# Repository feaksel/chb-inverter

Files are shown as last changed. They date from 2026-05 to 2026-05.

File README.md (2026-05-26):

# 5-Level Cascaded H-Bridge Inverter

<p align="center">
  Populated single-bridge v4 PCB module — IRFB4110 H-bridge with TLP250 optical gate drive and isolated MCP3201 sensing
  <br/>
  <sub><i>One of two identical single-bridge v4 modules — 4-layer JLCPCB, IRFB4110 power MOSFETs in a full H-bridge, TLP250 optical gate drive on a B0515S isolated 15 V rail, bit-banged MCP3201 sensing through 6N137 optocouplers. Cascading two of these externally produces the 5-level output shown below.</i></sub>
</p>

<p align="center">
  Oscilloscope: 100 V output with 5 distinct cascade levels — the project deliverable
  <br/>
  <sub><i>The headline result — 100 V output with 5 distinct cascade levels under sustained PSC-PWM at 5 kHz, no filter.</i></sub>
</p>

<p align="center">
  
  
  
  
  
</p>

Modular **5-level cascaded H-bridge multilevel inverter** built around two single-bridge PCB modules and an **STM32 Nucleo-F303RE** running **phase-shifted carrier PWM** at 5 kHz. Bench-validated, demonstrated, and now consolidated into a citable engineering record. Built as the **ELE 401/402 graduation project** at **Hacettepe University EEE** — Spring 2026.

> **Status:** Hardware fabricated, populated, and bench-validated. Firmware deployed. Five distinct cascade output levels confirmed on the oscilloscope at 100 V cascade output. Bridges thermally balanced under sustained load. **Demonstration successful.**

## Quick links

<table>
  <tr>
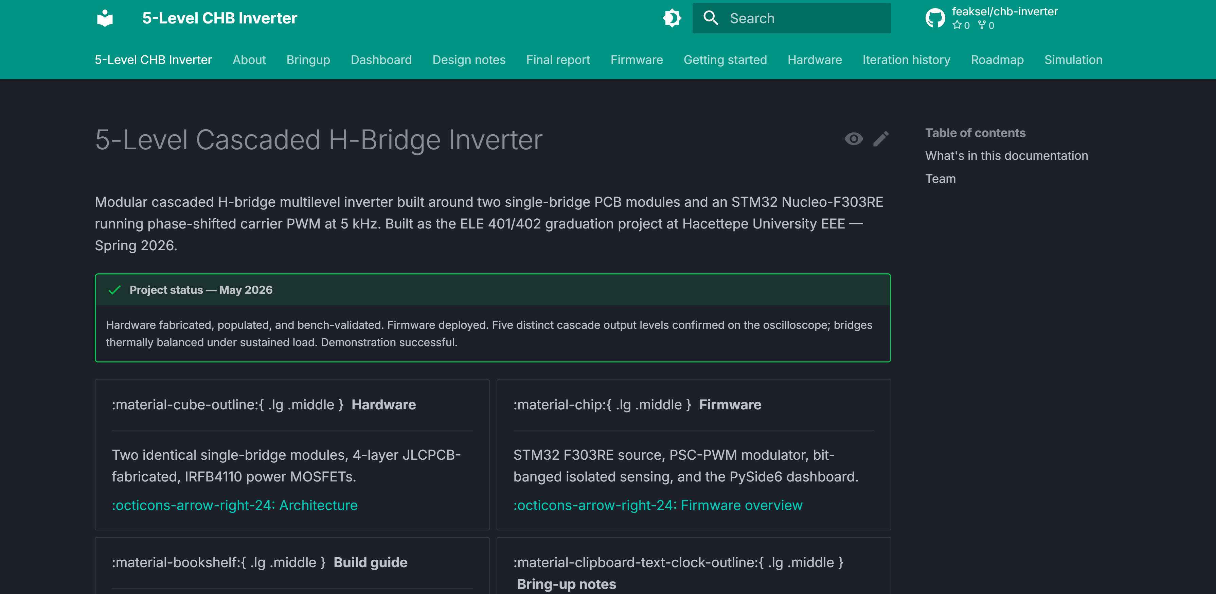
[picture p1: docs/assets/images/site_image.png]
    <td align="center" width="33%"><br/><b>Documentation site</b></td>
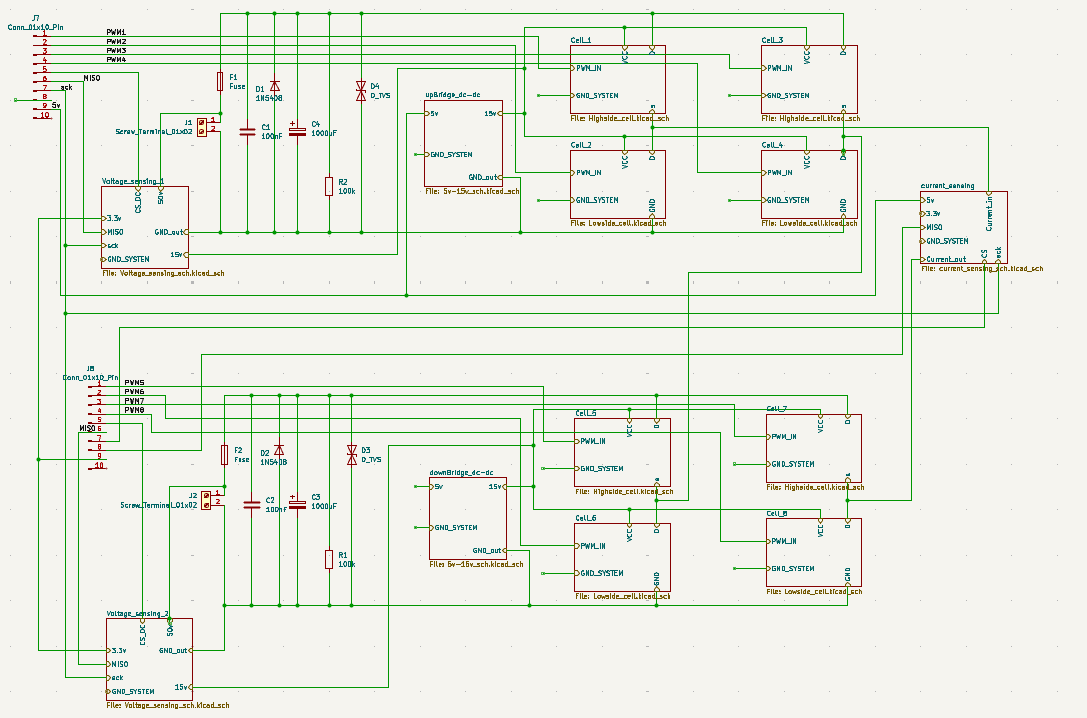
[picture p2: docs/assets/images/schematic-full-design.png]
    <td align="center" width="33%"><br/><b>Build Guide v4.0</b></td>
    <td align="center" width="33%"><br/><b>Final report</b></td>
  </tr>
  <tr>
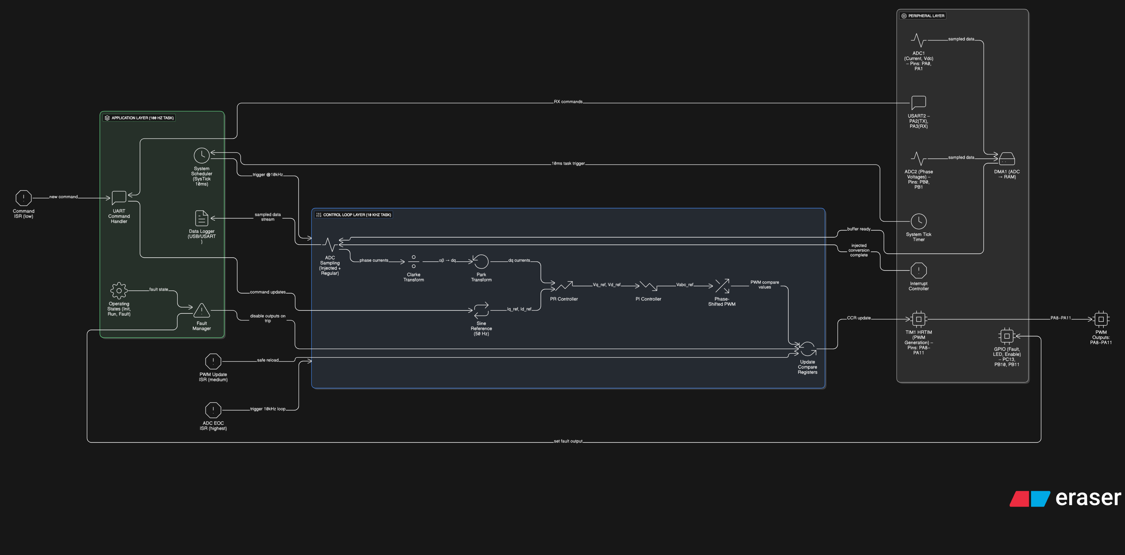
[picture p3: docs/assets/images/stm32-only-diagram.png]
    <td align="center"><br/><b>Firmware (STM32 + dashboard)</b></td>
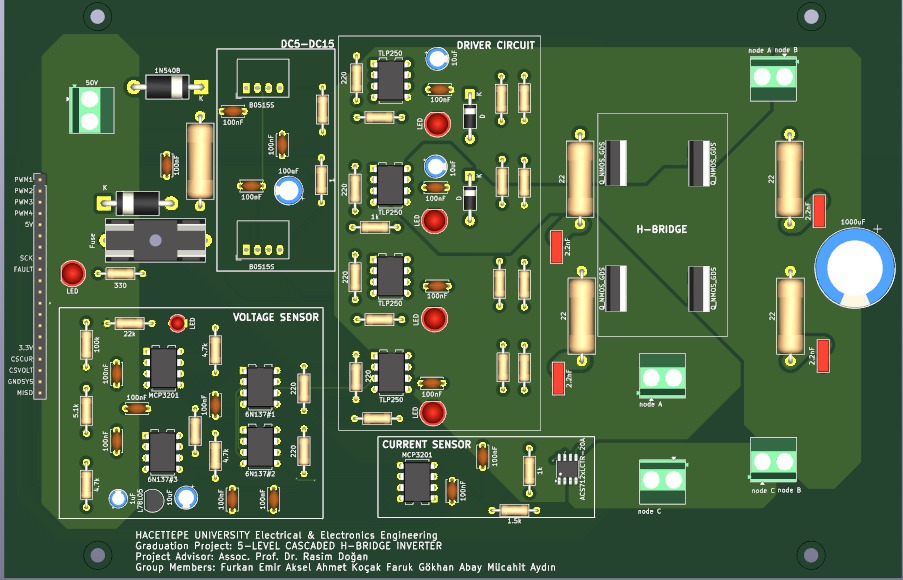
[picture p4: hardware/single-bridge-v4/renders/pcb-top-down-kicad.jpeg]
    <td align="center"><br/><b>Hardware (KiCad + BOM + gerbers)</b></td>
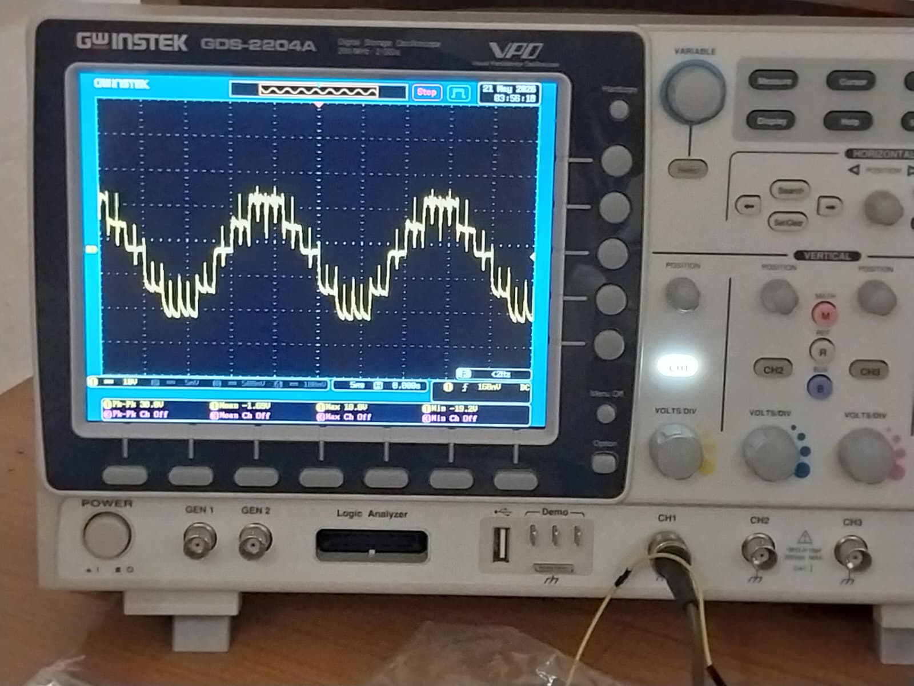
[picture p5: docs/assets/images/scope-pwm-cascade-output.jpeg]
    <td align="center"><br/><b>Bring-up session</b></td>
  </tr>
</table>

## What was built

Two identical **single-bridge PCB modules** (4-layer JLCPCB, **IRFB4110** power MOSFETs) cascaded to produce 5 distinct output voltage levels. The STM32 F303RE generates **phase-shifted carrier PWM** at 5 kHz with bit-banged **MCP3201** sensing isolated via **6N137** optocouplers. A **PySide6** desktop dashboard provides full operator control over UART.

<p align="center">
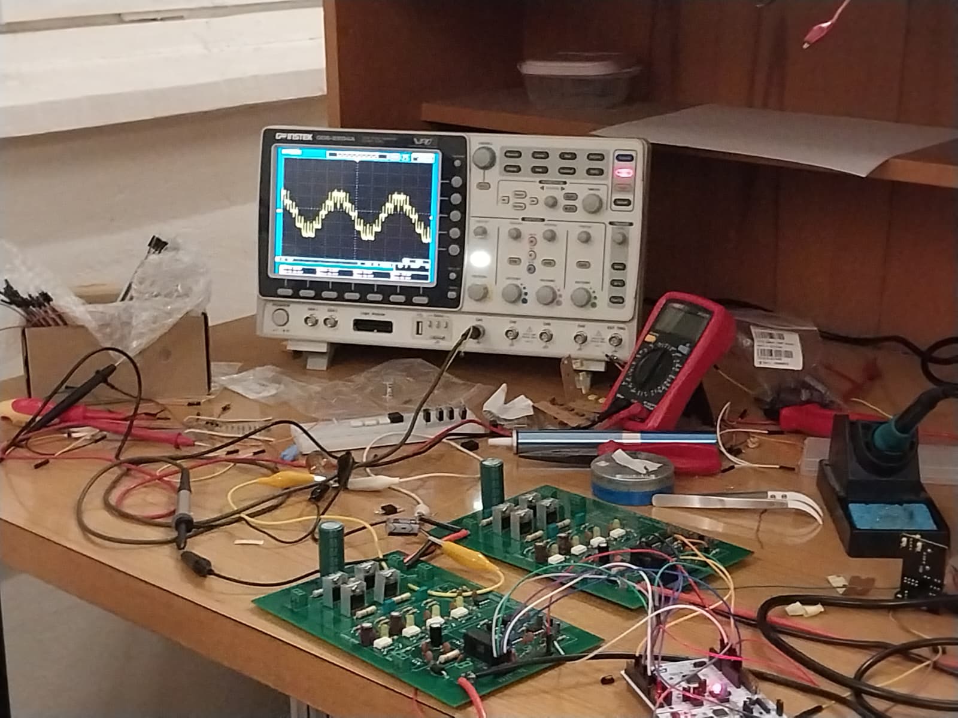
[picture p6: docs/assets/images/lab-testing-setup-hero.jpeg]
Lab testing setup — the two cascaded single-bridge modules wired into the bench rig
  
  <br/>
  <sub><i>Lab testing setup — the two cascaded single-bridge modules driven by the Nucleo, with the dashboard live on the bench PC.</i></sub>
</p>

The PSC modulation gives natural bridge-balance — both H-bridges carry equal switching load. The deviation from the build-guide's original IPD LS-PWM (which had inherent bridge-loss asymmetry) is documented in the [PSC vs. LSPWM design note](docs/design-notes/psc-vs-lspwm.md). The iteration story from the early IRFZ44N / IPD layouts through the as-built IRFB4110 / PSC design is in [iteration history](docs/iteration-history/).

## On the demo stand

<p align="center">
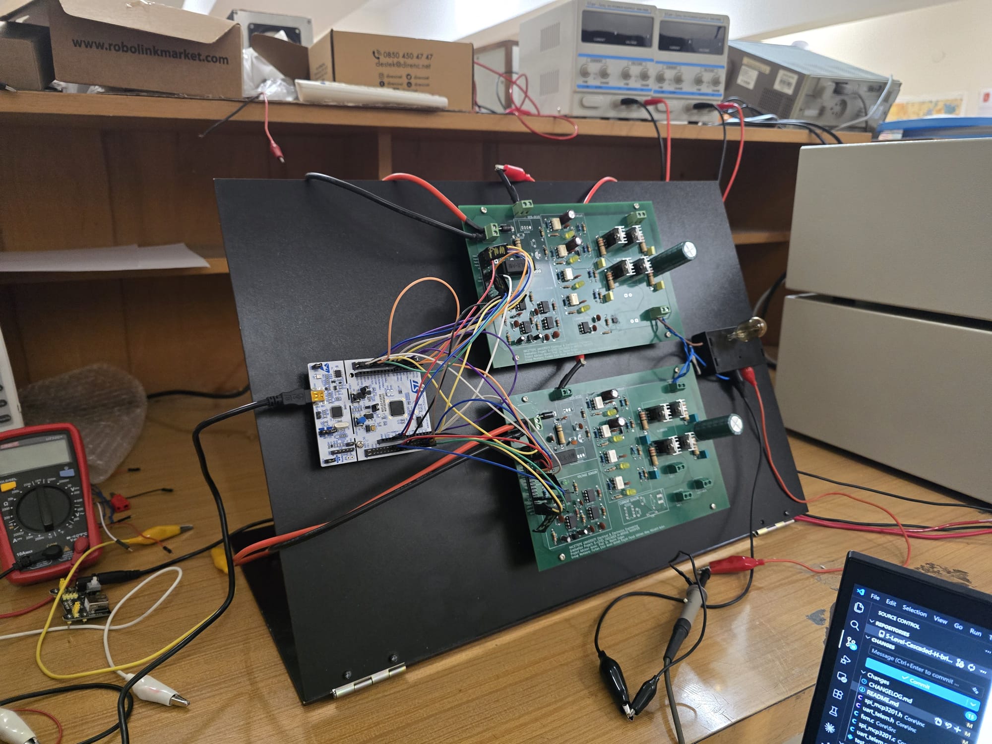
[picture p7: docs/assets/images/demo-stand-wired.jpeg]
The 5-level CHB inverter on the demo stand, fully wired
  
  <br/>
  <sub><i>Demo stand — the inverter wired into the bench supplies + load. Five levels visible on the scope as soon as the supplies were brought up.</i></sub>
</p>

## Team

**Project group "Cereyan Hacıları"** ("The Current Pilgrims"), under **Assoc. Prof. Dr. Rasım Doğan**.

<p align="center">
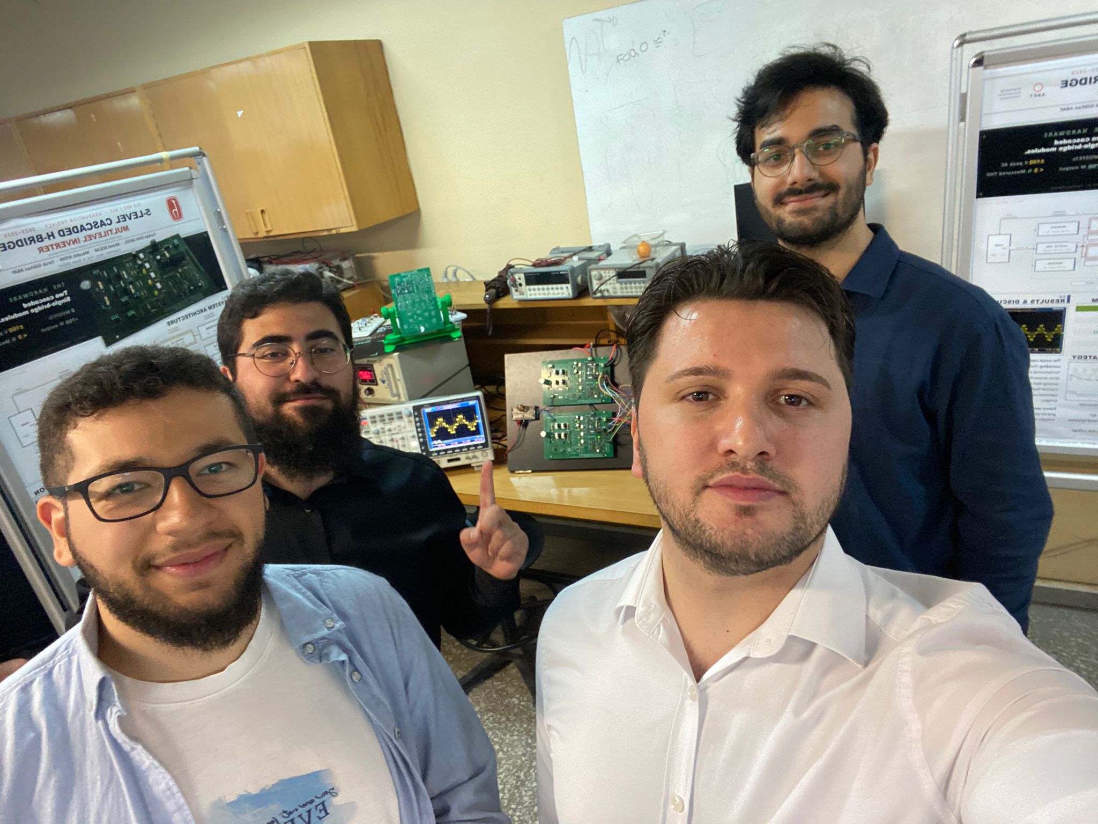
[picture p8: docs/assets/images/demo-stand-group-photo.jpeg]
Cereyan Hacıları on the demo stand
  
</p>

<table>
  <tr>
    <td align="center"><b>Furkan Emir Aksel</b><br/>Lead, firmware, dashboard</td>
    <td align="center"><b>Ahmet Koçak</b><br/>Hardware, bring-up</td>
    <td align="center"><b>Faruk Gökhan Abay</b><br/>Simulation, analysis</td>
    <td align="center"><b>Mücahit Aydın</b><br/>Hardware, assembly</td>
  </tr>
</table>

<p align="center">
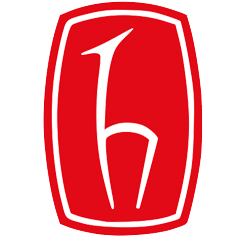
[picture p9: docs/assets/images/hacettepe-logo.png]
Hacettepe University
  
  <br/>
  <i>Hacettepe University, Department of Electrical and Electronics Engineering — Ankara, Türkiye, 2026.</i>
</p>

## Repository layout

```
chb-inverter/
├── docs/              # MkDocs Material source — every .md becomes a published page
│   ├── hardware/      # Architecture, build guide v4, BOM, schematic, PCB, photos
│   ├── firmware/      # Pin map, state machine, UART protocol, modulators, protection
│   ├── dashboard/     # Operator workflow, install, architecture
│   ├── simulation/    # Simulink THD analysis
│   ├── bringup/       # First-session + reference (rendered from firmware tree)
│   ├── design-notes/  # 5 design-decision deep-dives (bootstrap, isolation, PSC, IGBT, grounding)
│   ├── iteration-history/  # Per-iteration narrative (4 rounds, 1 → 4 as-built)
│   ├── roadmap/       # 6 future-work tracks
│   ├── final-report/  # Consolidated graduation report
│   └── about/         # Team, supervisor, institution, license
├── hardware/          # KiCad project, gerbers, BOM CSV, populated photos
├── firmware/          # STM32 source (git subtree, full history) + PySide6 dashboard
├── simulation/        # Simulink models (3 variants) + analysis
├── experimental/      # RISC-V SoC + FPGA controller — unverified tracks
├── tools/             # BOM validator, link checker, PCB renderer
└── tests/             # Repo-level CI tests
```

## License

Apache-2.0. See [LICENSE](LICENSE).

## Citation

If this project informs academic work, please cite it. The full citation metadata is in [CITATION.cff](CITATION.cff).

```bibtex
@software{aksel_2026_chb_inverter,
  author       = {Aksel, Furkan Emir and Koçak, Ahmet and Abay, Faruk Gökhan and Aydın, Mücahit},
  title        = {{5-Level Cascaded H-Bridge Inverter with STM32 Nucleo-F303RE}},
  year         = 2026,
  month        = 5,
  publisher    = {Hacettepe University, Department of Electrical and Electronics Engineering},
  version      = {1.0.0},
  url          = {https://github.com/feaksel/chb-inverter}
}
```

## Future / experimental work

The [`experimental/`](experimental/) directory contains exploratory tracks that were **not** validated in silicon and are **not** part of the graduation deliverable:

- [`experimental/risc-v-soc/`](experimental/risc-v-soc/) — A custom **RV32IM SoC** with integrated PWM / ADC / protection / UART / GPIO peripherals, taken through full **Cadence Genus → Innovus → GDSII** flow against the **SkyWater 130 nm PDK**. No tape-out; no FPGA equivalence check. Preserved for continuity.
- [`experimental/fpga-controller/`](experimental/fpga-controller/) — Placeholder for a future FPGA-based controller.

For the roadmap of work that _would_ extend the as-built inverter, see [`docs/roadmap/`](docs/roadmap/).

## Contributing

This repository was produced as a graduation project; it is **not** actively maintained for feature contributions. Issues and pull requests addressing documentation errata, bring-up procedure improvements, or porting to other STM32 variants are welcome. For substantive design changes, please open an issue first to discuss scope.

---

<p align="center">
  <sub>Built in Ankara, Türkiye · Spring 2026</sub>
</p>

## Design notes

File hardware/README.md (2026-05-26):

# Hardware

KiCad sources, gerbers, BOM, and photos for the as-built hardware.

| Path | Status |
|---|---|
| [`single-bridge-v4/`](single-bridge-v4/) | The board that was fabricated, populated, and demonstrated. Two identical modules cascaded. |
| [`legacy/`](legacy/) | Earlier design iterations preserved for the iteration-history narrative. Not for fabrication. |

The canonical engineering reference for everything in this directory is **[Build Guide v4.0](../docs/hardware/build-guide-v4.md)**.

## Conventions

- BOMs are CSV with these columns: `Reference`, `Quantity`, `Value`, `Footprint`, `MPN`, `Supplier`, `Supplier Part Number`, `Supplier URL`, `Unit Cost TL`.
- Suppliers are restricted to Turkish domestic vendors: Motorobit, Direnc.net, Robotistan, Komponentci.net.
- Passives default to through-hole (THT) for hand-assembly. Documented exceptions: ACS712 (SOIC-8), MCP3201 (DIP-8).
- Photos in `photos/` are tracked via Git LFS (see [`.gitattributes`](../.gitattributes)).

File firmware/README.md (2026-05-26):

# Firmware

STM32 firmware (CMSIS bare-metal with HAL bring-up shim) and the PySide6 operator dashboard for the 5-Level CHB Inverter.

The [`stm32-f303re/`](stm32-f303re/) tree is imported via `git subtree` from the upstream repository at https://github.com/feaksel/5-Level-Cascaded-H-bridge-Inverter-with-STM32-Nucleo-F303RE (branch `pwm-rewrite-configurable`). All upstream commits are preserved in this repo's `git log`.

## Quick reference

| Document | Where |
|---|---|
| Firmware README | [`stm32-f303re/README.md`](stm32-f303re/README.md) |
| Firmware CHANGELOG | [`stm32-f303re/CHANGELOG.md`](stm32-f303re/CHANGELOG.md) |
| Finite-state machine | [`stm32-f303re/FSM_NOTES.md`](stm32-f303re/FSM_NOTES.md) |
| First bench session | [`stm32-f303re/FIRST_BENCH_SESSION.md`](stm32-f303re/FIRST_BENCH_SESSION.md) |
| Hardware bring-up reference | [`stm32-f303re/HARDWARE_BRINGUP.md`](stm32-f303re/HARDWARE_BRINGUP.md) |
| Operator dashboard | [`stm32-f303re/dashboard/`](stm32-f303re/dashboard/) |

These files are also rendered into the [published docs site](https://feaksel.github.io/chb-inverter/) under [`docs/firmware/`](../docs/firmware/) and [`docs/bringup/`](../docs/bringup/) via `mkdocs-include-markdown-plugin`.

## Build and flash

### STM32CubeIDE (normal path)

1. Open `firmware/stm32-f303re/` in STM32CubeIDE 1.17+.
2. Build (`Project → Build All` or the hammer icon).
3. Plug in the Nucleo-F303RE over USB.
4. Flash with the Run/Debug button.

Expected size: ≈ 36 KB Flash, ≈ 4 KB RAM. Zero warnings under `-Wall -Wextra -Wshadow -Wundef`.

### Command-line / CI

The Phase 1 `firmware-build` GitHub Actions workflow runs `make` against `firmware/stm32-f303re/Debug/makefile` if present, and falls back to a per-file syntax check using `arm-none-eabi-gcc -fsyntax-only` otherwise. The full toolchain invocation that CubeIDE uses is documented in [`stm32-f303re/README.md`](stm32-f303re/README.md) under **Build and Flash → Command-line build**.

## Run the dashboard

The dashboard is a PySide6 desktop application that connects over UART (115200 8N1) and provides commands + 20 Hz telemetry visualization.

```powershell
cd firmware/stm32-f303re/dashboard
py -3.11 -m pip install -r requirements.txt
py -3.11 run_dashboard.py
```

> Use Python **3.11** for the dashboard. The pinned PySide6 wheel (`PySide6==6.5.3`) ships binaries for Python 3.7–3.11 and is not available on 3.12 yet.

The unit tests under `dashboard/tests/` are pure Python and run without Qt:

```powershell
cd firmware/stm32-f303re/dashboard
py -3 -m unittest discover tests -v
```

## Important runtime behaviors

- **Auto-start** — if no UART byte arrives within 3 s of boot, the firmware issues its own `START` using the defaults in [`Core/Inc/pwm_config.h`](stm32-f303re/Core/Inc/pwm_config.h). Sending any UART byte during those 3 s cancels auto-start permanently for that boot cycle. The dashboard's `SerialSource` transmits `STATUS` on connect (and on every detected `BOOT_SELF_TEST_DONE`) to suppress auto-start whenever an operator is present.
- **SPIINV** — every MCP3201 SPI line crosses the isolation barrier through a 6N137 optocoupler, which inverts. The `SPIINV <0..7>` UART command sets a per-line inversion mask at runtime. Once bench-validated, set `SPI_DEFAULT_INVERT_MASK` in [`Core/Inc/spi_mcp3201.h`](stm32-f303re/Core/Inc/spi_mcp3201.h) so the right polarity is the boot default.
- **VNOM scaling** — DC-bus protection thresholds (UV / OV / IMBAL) scale with the runtime `VNOM` setting (5–60 V). The factory default is 50 V. Bench-testing at 12 V is supported by setting `VNOM 12`.
- **OPEN sensing mode** is allowed (for hardware where the sensors aren't wired yet) but disables all protection and emits a UART warning.

Full per-command and per-state reference in [`docs/firmware/`](../docs/firmware/).

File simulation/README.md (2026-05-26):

# Simulation

Pre-hardware simulation work that informed the topology and modulation choices.

| Path | Contents |
|---|---|
| [`simulink/`](simulink/) | The 5-level CHB Simulink model (`.slx`) and the analysis scripts that consume its outputs. |
| [`matlab/`](matlab/) | Helper `.m` files used during analysis and report generation. |

The simulation predicted ~4.9% THD at the 5-level output before any LC filtering. That number is the headline result reported in the ELE 401 term report; the validated bench number lives in [`docs/simulation/thd-analysis.md`](../docs/simulation/thd-analysis.md).

> The Simulink work was a design-time aid, not a live model. It is not part of the production firmware or hardware flow.

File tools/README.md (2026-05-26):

# Tools

Repository maintenance scripts. Run from the repo root with `py -3.12 tools/<script>.py`.

| Script | Purpose | Phase added |
|---|---|---|
| `bom-validator.py` | Cross-checks `hardware/single-bridge-v4/bom.csv` against the KiCad netlist; flags missing supplier links and column-format errors. | Phase 3 |
| `render-pcb.py` | Wraps `kicad-cli pcb render` to produce top/bottom/isometric PNGs for the docs site. | Phase 3 |
| `docs-link-check.py` | Crawls the built MkDocs site and reports broken internal links. | Phase 1 |

These scripts have no external runtime dependencies beyond what `pyproject.toml` already pins for the docs build.

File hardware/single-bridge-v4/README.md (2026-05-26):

# single-bridge-v4

The PCB module that was fabricated, populated, and demonstrated. Two identical instances are cascaded to form the 5-level inverter.

## Specifications

| | |
|---|---|
| Layers | 4 (1 oz top/bottom, 0.5 oz inner) |
| Fabricator | JLCPCB |
| Power MOSFETs | IRFB4110 (×4 per module, full H-bridge) |
| Gate drive | IR2110 high/low-side with bootstrap |
| Sensing | MCP3201 12-bit ADC, isolated via 6N137 optocoupler (bit-banged SPI) |
| Current sense | ACS712 (×1 per module, on the bridge return) |
| Bridge supply | Independent isolated DC source per module |
| Logic supply | Common 5 V from the STM32 carrier |

Full reference: [Build Guide v4.0](../../docs/hardware/build-guide-v4.md).

## Subdirectories

| Path | Contents |
|---|---|
| [`kicad/`](kicad/) | KiCad project: schematic, board, libraries, footprints, 3D models. |
| [`gerbers/`](gerbers/) | JLCPCB-ready gerber ZIP and extracted per-layer artwork. |
| [`renders/`](renders/) | 3D PNG renders (top, bottom, isometric). Regenerable from `kicad/` via `tools/render-pcb.py`. |
| [`photos/`](photos/) | Populated-board photos and oscilloscope captures from bring-up. Tracked via Git LFS. |

## Files (to be added in Phase 3)

- `bom.csv` — fully populated BOM with Turkish supplier links.
- `pick-and-place.csv` — produced by KiCad.
- `stackup.md` — 4-layer stack details and the design rationale.

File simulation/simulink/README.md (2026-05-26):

# Simulink

The 5-level CHB Simulink models and analysis scripts.

| File | What it is |
|---|---|
| [`chb-5level-v1.slx`](chb-5level-v1.slx) | First-pass IPD LS-PWM model with ideal switches. Produced the headline **THD = 4.9 %** figure. |
| [`chb-5level-v2.slx`](chb-5level-v2.slx) | Added IR2110 vs. TLP250 gate-driver behavioural sweep — the simulation that killed the IR2110 path. |
| [`chb-5level-rl-nospike.slx`](chb-5level-rl-nospike.slx) | Adds LC filter + RL load + snubber-tuned switching (no V<sub>DS</sub> spike). |

All three models open in **MATLAB R2023b** (or later) with the **Simscape Electrical** toolbox.

## Run

```matlab
>> open('chb-5level-v1.slx');     % opens the model
>> sim('chb-5level-v1');           % runs simulation
>> thd(simout.OutputVoltage.Data, simout.OutputVoltage.Time(2) - simout.OutputVoltage.Time(1), 50)
ans = 4.9012
```

## Results

Simulation result captures, FFT plots, and THD CSV exports live in `results/` (currently empty — to be repopulated when the team next exports from MATLAB).

## See also

- [Simulation overview in the docs site](https://feaksel.github.io/chb-inverter/simulation/overview/)
- [THD analysis page](https://feaksel.github.io/chb-inverter/simulation/thd-analysis/)
- [Model architecture page](https://feaksel.github.io/chb-inverter/simulation/models/)

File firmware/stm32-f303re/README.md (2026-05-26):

# 5-Level Cascaded H-Bridge Inverter with STM32 Nucleo-F303RE

This project drives a 5-level cascaded H-bridge inverter using an STM32F303RE
(Nucleo-F303RE). TIM1 and TIM8 generate the complementary PWM bridge outputs;
the supervisory FSM adds sensing, protection, UART control, and telemetry.

## Highlights
- 5-level staircase output from two cascaded H-bridges
- Center-aligned complementary PWM with 3 us dead-time
- Bootstrap precharge before RUN
- MCP3201-based isolated DC bus sensing and safe-side current sensing
- Graceful sensing-mode fallback when sensors are missing or faulty
- Latched protection faults with safe PWM shutdown through `BDTR.MOE = 0`
- USART2 telemetry and line-based control over the ST-LINK virtual COM port

## Control Flow
1. System init sets clock, SysTick, LUT, GPIO, timers, sensor GPIO, UART, TIM6,
   NVIC, and the FSM.
2. TIM1 update interrupt calls `Pwm_TIM1_UpdateHandler` (in
   [Core/Src/pwm_modulator.c](Core/Src/pwm_modulator.c)) which dispatches
   to the active modulator (STAIR or PSC) and owns all PWM duty content.
3. TIM6 runs at 1 kHz and only sets `g_sense_pending`; sensor reads happen in
   the main loop.
4. The main loop runs `FSM_Run()`, which handles commands, sensing, protection,
   state transitions, and 20 Hz telemetry.

## Key Parameters
PWM defaults are in [Core/Inc/pwm_config.h](Core/Inc/pwm_config.h); most
are runtime-configurable over UART (see PWM commands below):
- Modulator: `STAIR` (default), `PSC`, or `STAIR_ALT` — set with `MOD`
- Switching frequency: 500 Hz default — set with `FSW` (100–20000 Hz)
- Fundamental frequency: 50 Hz default — set with `FFUND`
- Modulation index: 0.95 default — set with `MI` (0.0–0.95)
- Bridge select: `BOTH` default — set with `BRIDGE` (BOTH/B1/B2)

Compile-time PWM constants in [Core/Src/pwm_modulator.c](Core/Src/pwm_modulator.c):
- Sine LUT size: 256 samples
- Dead-time: 3 us (`PWM_DEAD_TIME_DTG`, sized for the IRFB4110 power stage)
- Bootstrap precharge: 6 ms

Protection threshold defaults are in [Core/Inc/protection.h](Core/Inc/protection.h)
and correspond to the default 50 V nominal bus. They are runtime-adjustable
with `VNOM` / `OC` (see UART commands below):
- DC undervoltage: 40.0 V (`0.80 × VNOM`)
- DC overvoltage: 58.0 V (`1.16 × VNOM`)
- DC imbalance: 10.0 V (`0.20 × VNOM`)
- Overcurrent: 15.0 A (independent of VNOM)

## Pinout

### PWM Outputs
| Signal | Timer channel | Pin |
|---|---|---:|
| PWM_1H | TIM1_CH1 | PA8 |
| PWM_1L | TIM1_CH1N | PA7 |
| PWM_2H | TIM1_CH2 | PA9 |
| PWM_2L | TIM1_CH2N | PA12 |
| PWM_3H | TIM8_CH1 | PB6 |
| PWM_3L | TIM8_CH1N | PB3 |
| PWM_4H | TIM8_CH2 | PB8 |
| PWM_4L | TIM8_CH2N | PB0 |

### Sensing, UART, and fault output
| Signal | Pin | Notes |
|---|---:|---|
| SCK | PA5 | Bit-banged MCP3201 clock, held at or below 1 MHz |
| CS_DC1 | PC0 | DC bus 1 MCP3201 chip select |
| CS_DC2 | PC1 | DC bus 2 MCP3201 chip select |
| CS_CUR | PC2 | Current MCP3201 chip select |
| MISO_DC1 | PA6 | Lower-bridge island MISO (DC1 ADC only) |
| MISO_DC2 / MISO_CUR | PC3 | Upper-bridge island MISO — DC2 ADC and current ADC share this wire |
| USART2_TX | PA2 | ST-LINK VCP TX, 115200 8N1 |
| USART2_RX | PA3 | ST-LINK VCP RX, 115200 8N1 |
| FAULT_OUT | PB5 | Active-low hardware fault flag (LOW = fault latched) |

This board uses **two** MCP3201 MISO return lines, not three. The lower-bridge
island returns DC1 on PA6. The upper-bridge island carries both the DC2 ADC
and the current ADC on a single wire-shared isolated return on PC3 — each ADC
keeps its own chip select, and the firmware reads strictly one channel at a
time (one CS asserted) so the two never drive the shared wire together.
PC4 is unused.

`FAULT_OUT` (PB5) is an active-low GPIO the firmware pulls LOW whenever a
fault is latched and releases HIGH on return to IDLE — for an indicator LED
or an external interlock. It corresponds to build guide v3.1 header pin 16.

### SPI line inversion (`SPIINV`)
Each MCP3201 SPI line crosses the isolation barrier through a 6N137
optocoupler, which **inverts** (LED on → output low). If your board has an
odd number of inverting stages in a line, the firmware must drive/read that
line inverted to cancel it. `SPIINV <mask>` sets this at runtime — bit 0 =
SCK, bit 1 = CS, bit 2 = MISO:

- `SPIINV 0` — direct drive, no inversion (power-on default)
- `SPIINV 7` — all three lines inverted (standard one-6N137-per-line wiring)
- other values invert individual lines for unusual mixed wiring

`SPIINV` also auto-runs the sensor self-test (like `RESCAN`) so you see
immediately whether the sensors come alive. The active mask is reported in
the `STATUS` line as `spiinv=0xN`. Once you know the right value, set
`SPI_DEFAULT_INVERT_MASK` in [Core/Inc/spi_mcp3201.h](Core/Inc/spi_mcp3201.h)
to make it the power-on default.

## Sensing Modes
| ID | Mode | Sensors used | Active protection |
|---:|---|---|---|
| 0 | `FULL` | DC1, DC2, current | UV, OV, OC, imbalance |
| 1 | `DC_ONLY` | DC1, DC2 | UV, OV, imbalance |
| 2 | `CUR_ONLY` | Current | OC |
| 3 | `OPEN` | None | None |
| 4 | `DC1` | DC1, optional current | DC1 UV/OV, plus OC if current is available |
| 5 | `DC2` | DC2, optional current | DC2 UV/OV, plus OC if current is available |

At boot, each ADC is read four times. Sensors stuck at `0x000` or `0xFFF` are
marked unavailable, and the FSM auto-demotes to the most capable supported mode.
`OPEN` mode is allowed for demos but disables all protection and emits a UART
warning when selected or started.

## UART Commands
Commands are line-based and terminated by `\n` or `\r\n`.

| Command | Allowed states | Effect |
|---|---|---|
| `START` | IDLE | Enable MOE and enter PRECHARGE, then RUN |
| `STOP` | PRECHARGE, RUN | Disable MOE and return to IDLE |
| `CLEAR` | FAULT | Clear latched fault only after the active condition is gone |
| `MODE <0..5>` | IDLE, FAULT | Select sensing mode if required sensors are available |
| `STATUS` | Any | Print one human-readable status line |
| `HELP` | Any | Print command summary |
| `MI <0.0-0.95>` | IDLE | Override modulation index |
| `RESCAN` | IDLE, FAULT | Re-run the ADC self-test and re-mark sensors available |
| `MOD STAIR\|PSC\|STAIR_ALT` | IDLE | Pick modulator (STAIR = 500 Hz staircase, PSC = phase-shifted carriers, STAIR_ALT = bridge-balanced staircase) |
| `FSW <hz>` | IDLE | Set switching frequency (100..20000 Hz) |
| `BRIDGE BOTH\|B1\|B2` | IDLE | Single-bridge test mode (inactive bridge freewheels) |
| `FFUND <hz>` | IDLE | Set fundamental frequency (10..400 Hz) |
| `VNOM <v>` | IDLE, FAULT | Set nominal per-bridge bus voltage (5..60 V); derives UV/OV/IMBAL thresholds |
| `OC <a>` | IDLE, FAULT | Set overcurrent trip threshold (0.5..20 A) |
| `SPIINV <0..7>` | IDLE, FAULT | Set MCP3201 SPI line-inversion mask, then auto-rescan sensors |
| `ADCRAW` | Any | One-shot raw MCP3201 read; reports `$R,dc1=N,dc2=N,cur=N` (0..4095) |
| `TRIP` | IDLE, PRECHARGE, RUN | Operator-forced fault — latches `FAULT_MANUAL`, enters FAULT, drives FAULT_OUT low |
| `CONFIG` | Any | Print active PWM (`$C`) and protection (`$P`) config lines |

Accepted commands echo as `$A,<cmd>\r\n`. Rejected commands return
`$E,<reason>\r\n`. PWM-config changes additionally emit a fresh `$C,...`
line and protection-config changes emit a `$P,...` line, so the dashboard
log always reflects the live configuration.

### Configurable protection thresholds
The DC-bus protection thresholds are not fixed — they scale with a single
nominal bus voltage so the inverter can be bench-tested below the 50 V
design point (e.g. a 12 V supply) without the undervoltage trip firing
immediately. `VNOM <v>` sets the nominal voltage; the firmware derives:

- undervoltage = `0.80 × VNOM`
- overvoltage = `1.16 × VNOM`
- imbalance = `0.20 × VNOM`

At `VNOM 50` the derived thresholds are 40 / 58 / 10 V — the original
fixed design values. At `VNOM 12` they become 9.6 / 13.9 / 2.4 V.
Overcurrent (`OC`) is independent of VNOM because it is a load property.
The active protection config is reported on the `$P` line:
`$P,vnom=12.00,uv=9.60,ov=13.92,oc=15.00,imbal=2.40`.

**Auto-start.** If no UART byte is received within 3 s after boot, the
firmware issues its own `START` using the defaults from
[Core/Inc/pwm_config.h](Core/Inc/pwm_config.h) (`STAIR / 500 Hz / BOTH /
MI 0.95 / 50 Hz`) and emits `$A,AUTO_START`. Sending any UART byte during
those 3 s cancels auto-start permanently and the system waits for an
explicit `START`. This lets the inverter run standalone for demos while
preserving the explicit-arm behavior whenever an operator is at the keyboard.

## Telemetry
Telemetry is emitted at 20 Hz:

```text
$T,<ms>,<state>,<mode>,<fault>,<vdc1>,<vdc2>,<iout>,<level>*<chk>\r\n
```

`<chk>` is the 8-bit XOR of bytes between `$` and `*`, printed as two hex
characters. Fault bits are `0x01=UV`, `0x02=OV`, `0x04=OC`, `0x08=IMBAL`, and
`0x10=SENSOR_LOST`. Unused or unavailable channels print `NAN`.

Example:

```text
$T,12345,RUN,FULL,0x00,49.87,50.02,3.41,1*7B
```

## Build and Flash

### CubeIDE (normal workflow)
1. Open the project in STM32CubeIDE 1.17+.
2. Build the project (`Project → Build All` or hammer icon).
3. Connect the Nucleo-F303RE over USB.
4. Run or debug to flash the target.

The CubeIDE project source paths cover the whole `Core/` and `Drivers/`
trees, so new files under `Core/Src` and `Core/Inc` are picked up
automatically by the auto-discovery build.

### Command-line build (CI / verification)
Uses the same compiler CubeIDE ships, no project import needed:

```
GCC=/c/ST/STM32CubeIDE_<version>/STM32CubeIDE/plugins/com.st.stm32cube.ide.mcu.externaltools.gnu-tools-for-stm32.<ver>/tools/bin/arm-none-eabi-gcc.exe
CFLAGS="-mcpu=cortex-m4 -mfpu=fpv4-sp-d16 -mfloat-abi=hard -mthumb \
        -DDEBUG -DUSE_HAL_DRIVER -DSTM32F303xE \
        -ICore/Inc -IDrivers/STM32F3xx_HAL_Driver/Inc/Legacy \
        -IDrivers/STM32F3xx_HAL_Driver/Inc \
        -IDrivers/CMSIS/Device/ST/STM32F3xx/Include -IDrivers/CMSIS/Include \
        -O0 -g3 -Wall -Wextra -ffunction-sections -fdata-sections"
LDFLAGS="-mcpu=cortex-m4 -mfpu=fpv4-sp-d16 -mfloat-abi=hard -mthumb \
         -TSTM32F303RETX_FLASH.ld -Wl,--gc-sections -static \
         --specs=nano.specs --specs=nosys.specs -u_printf_float \
         -Wl,--start-group -lc -lm -Wl,--end-group"

mkdir -p build
for f in Core/Src/*.c Drivers/STM32F3xx_HAL_Driver/Src/*.c; do
  "$GCC" $CFLAGS -c "$f" -o "build/$(basename "$f" .c).o"
done
"$GCC" $CFLAGS -c Core/Startup/startup_stm32f303retx.s -o build/startup.o
"$GCC" $LDFLAGS build/*.o -o build/5levelchb.elf
# Optional: generate flashable formats
"${GCC%gcc.exe}objcopy.exe" -O binary build/5levelchb.elf build/5levelchb.bin
"${GCC%gcc.exe}objcopy.exe" -O ihex   build/5levelchb.elf build/5levelchb.hex
"${GCC%gcc.exe}size.exe"               build/5levelchb.elf
```

Expected output for the current branch: ~36 KB Flash, ~4 KB RAM, zero
warnings under `-Wall -Wextra -Wshadow -Wundef`.

### Flashing without CubeIDE
- **Drag and drop:** plug in the Nucleo, a USB drive named `NODE_F303RE`
  appears, copy `build/5levelchb.bin` onto it. ST-LINK does the rest.
- **STM32CubeProgrammer CLI:**
  `STM32_Programmer_CLI.exe -c port=SWD -w build/5levelchb.hex -rst`

## Dashboard tests
The dashboard parser and simulator have unit tests that do **not** require
PySide6, pyserial, or pyqtgraph and run in under a second:

```
cd dashboard
py -3 -m unittest discover tests -v
```

Current branch ships 19 tests covering the NMEA parser, fault encoding,
all FSM states/modes, the scenario simulator, and the new PWM-config
setters (modulator / FSW / bridge / fundamental frequency).

## Hardware bringup
Two docs cover bench testing:

- **[FIRST_BENCH_SESSION.md](FIRST_BENCH_SESSION.md)** — focused linear
  walkthrough for your first time on the bench with the new branch.
  Folds git pull, dashboard setup, flashing, and all three modulator
  tests (STAIR / STAIR_ALT / PSC) into one continuous procedure with
  explicit pass/fail checkpoints and TLP250-protection checks at every
  step. Start here.
- **[HARDWARE_BRINGUP.md](HARDWARE_BRINGUP.md)** — comprehensive
  phase-by-phase reference. Build-guide-style coverage of every test
  phase, what to expect, what the firmware emits on UART, scope
  captures, troubleshooting trees. Consult when something doesn't
  match the first-session doc.

Read at least the first one before applying any DC bus voltage.

## Notes and Safety
- This project drives power stages. Use proper gate drivers, isolation, and
  protection before applying high voltage.
- Verify dead-time, bootstrap timing, and sensor scaling on your hardware.
- `OPEN` mode is intentionally unprotected and should be used only for limited
  low-risk demos.

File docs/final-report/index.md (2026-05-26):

---
title: Final graduation report
---

# Final graduation report — 5-Level Cascaded H-Bridge Inverter

<p align="center">
  CHB Inverter project poster
  <br/>
  <sub><i>The project poster — a one-page summary of the work. Downloadable as <a href="../assets/pdfs/CHB_Inverter_Poster_v5.pdf">PDF</a> or <a href="../assets/pdfs/CHB_Inverter_Poster.pptx">editable PowerPoint</a>.</i></sub>
</p>

!!! tip "Download the formatted PDF"
    The final report is also available as a **formatted PDF** that follows the ELE 402 template structure (title page, abstract, TOC, list of figures, all 12 numbered sections, references):
    
    👉 **[Download `ELE402_Spring2026_FR_CereyanHacilari.pdf`](../assets/pdfs/ELE402_Spring2026_FR_CereyanHacilari.pdf)** (37 pages, 14 MB)
    
    The PDF is generated from [`tools/generate-final-report.py`](https://github.com/feaksel/chb-inverter/blob/main/tools/generate-final-report.py) and is regenerable from the canonical source material in the repo. The Markdown rendering on this page is the same content in browseable form.

This report **supersedes** the ELE 401 interim report (Fall 2025) and the ELE 402 interim report v4 (Spring 2026). Both source documents are preserved verbatim at [`docs/assets/pdfs/`](https://github.com/feaksel/chb-inverter/tree/main/docs/assets/pdfs).

**Authors:** Cereyan Hacıları — Furkan Emir Aksel, Ahmet Koçak, Faruk Gökhan Abay, Mücahit Aydın.
**Supervisor:** Assoc. Prof. Dr. Rasım Doğan.
**Institution:** Hacettepe University, Department of Electrical and Electronics Engineering — Ankara, Türkiye.
**Date:** May 2026.

---

## 1. Abstract & project summary

This report documents the design, fabrication, firmware development, bench validation, and demonstration of a **single-phase 5-level cascaded H-bridge (CHB) multilevel inverter**, built as the ELE 401/402 graduation project at Hacettepe University EEE during the 2025–26 academic year. The system uses **two identical single-bridge PCB modules** (4-layer JLCPCB-fabricated, **IRFB4110** N-channel MOSFETs) cascaded externally so their AC outputs sum to five distinct voltage levels at the inverter terminals. The controller is an **STM32 Nucleo-F303RE** running **phase-shifted carrier PWM (PSC-PWM)** at 5 kHz with hardware-enforced 3 µs dead time. Isolated bit-banged **MCP3201** SPI ADCs sense per-bridge DC bus voltages and output current via **6N137** optocouplers; an **isolated 5 V → 15 V B0515S DC-DC** supplies the **TLP250** optical gate drivers per bridge so that no bridge ever shares a ground reference with the controller. A **PySide6** desktop dashboard provides full operator control, 20 Hz telemetry visualization, replay, and a PC-only fault-scenario simulator.

The headline bench result: **five distinct cascade output levels visible on the oscilloscope at 100 V cascade output**, under sustained 5 kHz PSC-PWM operation with no output filter; both bridges thermally matched within ≈ 3 °C; no false sensor-loss or protection-trip events across multi-minute runs. The project converged to this configuration over four hardware iterations — earlier rounds (single dual-bridge PCB, IRFZ44N MOSFETs, IPD level-shifted PWM) surfaced V<sub>DSS</sub>-headroom problems, bootstrap-timing failures, isolation-defeating grounding errors, and bridge-loss asymmetry that all compounded into the iteration-4 re-architecture. The narrative of those four iterations and the design decisions behind each correction is the bulk of this report.

---

## 2. System architecture

### 2.1 Topology

Cascaded H-Bridge (CHB) multilevel topology connects N full-bridge cells in series, each generating three voltage levels (+V<sub>DC</sub>, 0, −V<sub>DC</sub>); the series connection produces (2N + 1) distinct output voltage levels. For **N = 2 cells** this project, the output levels are **{−2V<sub>DC</sub>, −V<sub>DC</sub>, 0, +V<sub>DC</sub>, +2V<sub>DC</sub>}** — five distinct levels. At the nominal 50 V bus per cell, the cascade output swings ±100 V.

Compared to the two other multilevel inverter topologies considered — Neutral Point Clamped (NPC) and Flying Capacitor (FC) — CHB is the most modular: each cell is mechanically and electrically interchangeable, with its own isolated DC source. NPC requires clamping diodes and has complex voltage-balancing dynamics; FC requires large pre-charged capacitors and has aging issues. CHB's "isolated DC source per cell" requirement — usually flagged as a constraint — is actually an advantage for renewable-energy integration, where independent PV strings or battery packs naturally supply isolated DC. Detailed topology selection rationale is preserved verbatim in [ELE 401 interim §6.1](https://github.com/feaksel/chb-inverter/blob/main/docs/assets/pdfs/ELE401_Fall2025_IR.pdf).

### 2.2 System block diagram

```mermaid
flowchart LR
    DC1["DC supply #1<br/>(isolated)"] --> B1["Bridge 1 module<br/>(single-bridge v4 PCB)"]
    DC2["DC supply #2<br/>(isolated)"] --> B2["Bridge 2 module<br/>(single-bridge v4 PCB)"]
    B1 --> SUM["AC sum<br/>(series cascade)"]
    B2 --> SUM
    SUM --> LOAD["Load / scope"]

    MCU["STM32 Nucleo-F303RE<br/>controller"]
    DASH["PySide6 dashboard<br/>(USART2 / VCP)"]
    MCU <-->|UART 115200 8N1| DASH

    MCU -->|TIM1 PWM<br/>+ dead-time| B1
    MCU -->|TIM8 PWM<br/>+ dead-time| B2

    B1 -->|MCP3201<br/>over 6N137| MCU
    B2 -->|MCP3201<br/>over 6N137| MCU

    FAULT["FAULT_OUT (PB5)<br/>active-LOW"]
    MCU --> FAULT
```

The full architectural detail is in [docs/hardware/architecture](../hardware/architecture.md); the diagram above is the report-scale view.

### 2.3 The isolation architecture

CHB topology imposes an **absolute requirement** for galvanic isolation between every bridge above the ground-referenced cell and the controller. The reason: in a cascaded topology, the upper bridge's source nodes float at the cascade-output voltage minus their own bridge voltage — at peak this is +100 V relative to controller ground at 5 kHz. Bootstrap-based gate drivers (IR2110 and similar) cannot supply gate voltage referenced to a floating V<sub>S</sub> that never returns to true ground each PWM period; their bootstrap capacitor reverse-biases continuously and the gate drive collapses. This was simulation-validated in Simulink with an IR2110 behavioural model before any silicon was committed (see [§5.1](#51-iteration-1) and [chb-isolation design note](../design-notes/chb-isolation.md)).

The as-built system implements isolation at four interfaces, each per bridge:

| Barrier | Component | Spec |
|---|---|---|
| Gate drive | TLP250 optical | 2.5 kV galvanic, LED → photodetector + MOSFET output |
| Gate supply | B0515S DC-DC | 1 W, 5 V → 15 V, ≥ 3 kV isolation per part |
| ADC clock + chip-select | 6N137 optocoupler | 10 Mbit/s — one per signal |
| ADC data return | 6N137 optocoupler | Same — independent line for MISO |

A subtle point: **both** modules in the as-built design implement full isolation, even though Bridge 1 (the lower cell) is strictly ground-referenced and could in principle skip it. The reason is modularity — two identical boards means one fab order, one stock SKU, and either module can serve as the bench-test instance during bring-up. The ≈ 50 TL per module of isolation parts is the cost of that interchangeability. We considered it worth it.

### 2.4 Operator interaction

The controller exposes a single USART2 link (115200 8N1) over the Nucleo's ST-LINK virtual COM port. A line-based command protocol gives the operator runtime control over every relevant parameter — modulator selection (`MOD STAIR|PSC|STAIR_ALT`), switching frequency (`FSW 100..20000` Hz), fundamental frequency (`FFUND 10..400` Hz), modulation index (`MI 0.0..0.95`), per-bridge isolation (`BRIDGE BOTH|B1|B2`), nominal bus voltage for protection scaling (`VNOM 5..60`), and overcurrent trip (`OC 0.5..20` A). A 20 Hz telemetry frame returns state, sensing mode, fault bits, all sensor values, and the current modulator level. Each PWM-config change emits a fresh `$C,...,lock=OK|BAD` line so the operator can confirm the carrier phase is locked before arming the bridge.

The full UART command set + telemetry frame format is documented at [docs/firmware/uart-protocol](../firmware/uart-protocol.md). The PySide6 dashboard handles all of these commands through a GUI, with an explicit `Arm live START` checkbox gating any command that would energize the bridges.

---

## 3. Hardware design

### 3.1 Power stage — IRFB4110

| Parameter | IRFB4110 (as-built) | IRFZ44N (v3.1, superseded) |
|---|---|---|
| V<sub>DSS</sub> | 100 V | 55 V |
| Continuous I<sub>D</sub> | 180 A @ 25 °C | 49 A @ 25 °C |
| R<sub>DS(on)</sub> @ V<sub>GS</sub> = 10 V | 4.5 mΩ | 17.5 mΩ |
| Total gate charge Q<sub>G</sub> | ≈ 150 nC | ≈ 67 nC |
| Package | TO-220AB | TO-220AB |

The MOSFET-vs-IGBT analysis at the project's operating point (50 V bus, 5 kHz switching, ≈ 400 W) is unambiguous in favour of MOSFETs — every loss term wins. The detail and the arithmetic are in the [IGBT vs. MOSFET design note](../design-notes/igbt-vs-mosfet.md); summary:

- **MOSFET conduction loss** at 5 A RMS: 5² × 0.0045 ≈ **0.11 W per device**. IGBT (V<sub>CE(sat)</sub> ≈ 1.4 V): **7.0 W per device** — a 63× difference.
- **MOSFET switching loss** at 5 kHz, 25 V, 7 A: ≈ **0.19 W per device**. IGBT with tail current: ≈ **5 W per device**.
- **System-wide power-stage loss**: MOSFET ≈ 2.4 W (≈ 99.4 % efficiency), IGBT ≈ 96 W (≈ 80 % efficiency).

The IRFZ44N → IRFB4110 swap happened mid-project (between iterations 3 and 4) for three independent reasons. **V<sub>DSS</sub> headroom**: a 55 V part on a 50 V bus has only ≈ 10 % nominal headroom, which gate-loop ringing easily exceeds. **TVS / V<sub>DSS</sub> mismatch**: the 1.5KE62A TVS clamps at 84.5 V — *above* the IRFZ44N V<sub>DSS</sub>, meaning a TVS-firing event would damage the MOSFETs anyway. **Conduction loss**: 4.5 mΩ vs. 17.5 mΩ is 4× lower, giving meaningful thermal headroom for an unenclosed bench prototype. The trade is the firmware's dead time, which had to rise from 2 µs (IRFZ44N) to **3 µs** (IRFB4110, BDTR.DTG = 0xA0) to accommodate the ~2× larger gate charge.

### 3.2 Gate drive — TLP250 + B0515S

Eight TLP250 optocouplers (one per MOSFET) provide 2.5 kV galvanic isolation between the controller's PWM outputs and the MOSFET gates. Each TLP250 has its output stage powered from a per-bridge isolated 15 V rail produced by a B0515S 5 V → 15 V isolated DC-DC converter. The 22 Ω gate series resistor and the 10 kΩ gate-source pull-down per MOSFET keep gate ringing controlled and ensure the MOSFET is held off whenever the driver is unpowered.

Bootstrap drive (IR2110) is **not used** anywhere in this design. The reasoning is detailed in the [bootstrap-fundamentals](../design-notes/bootstrap-fundamentals.md) and [CHB-isolation](../design-notes/chb-isolation.md) design notes; the short version is that bootstrap requires the high-side source to return to ground each PWM period to refresh the bootstrap cap, which the upper bridge in a cascaded topology never does. Iteration 2 confirmed this experimentally in addition to the Simulink prediction.

The TLP250 is non-inverting (LED ON → output HIGH → MOSFET ON). Combined with `BDTR.OSSI = 1` on the STM32 advanced timers, this means every state where the firmware *thinks* a bridge is off actually drives all four MOSFETs of that bridge off — including at boot, on fault, and on PWM disable. This safety property is preserved across every firmware state.

### 3.3 Sensing — MCP3201 + ACS712 + 6N137

DC bus voltage and output current are read by **MCP3201** 12-bit successive-approximation ADCs on the floating-bridge side. SPI signals (SCK, CS, MISO) cross the isolation barrier through dedicated **6N137** optocouplers per line. ACS712 Hall-effect current sensors (100 mV/A, 2.5 V zero offset) provide the per-bridge AC current sense.

A few specifics that became important during bring-up:

- **The 6N137 inverts** (LED on → output low). The firmware drives and reads each SPI line through an adjustable inversion mask — the `SPIINV <0..7>` runtime command (bit 0 = SCK, bit 1 = CS, bit 2 = MISO). Without this, an odd number of inverting stages causes the MCP3201 to see a backward clock or chip-select and return garbage. `SPIINV 7` (all three lines inverted) is the standard one-6N137-per-line wiring.
- **The two bridges share isolated MISOs asymmetrically.** The lower-bridge island has one MCP3201 (DC1) on its own MISO line. The upper-bridge island has two MCP3201s (DC2 and current) that wire-share a single isolated MISO return. The firmware reads strictly one channel at a time, per chip-select, to avoid bus contention — this was a mid-project rewrite of the original "3-independent-MISO" assumption (see [iteration-3](../iteration-history/iteration-3.md)).
- **The MCP3201 frame layout** is `[NULL][B11..B0][X][X][X]` — the firmware extracts the 12 data bits with `(raw >> 3) & 0x0FFF`. This is documented in Build Guide v3.1 §7.3, with a bringup-verification comment in the firmware that explains how to swap to `>> 1` if a known DC input reads ~8× off.

### 3.4 Protection chain

| Element | Purpose | Trip threshold |
|---|---|---|
| **1.5KE62A TVS** (per DC bus) | Clamp switching spikes below MOSFET V<sub>DSS</sub> | 84.5 V clamp (sits below IRFB4110's 100 V V<sub>DSS</sub>) |
| **15 A blade fuse** (per DC input) | Short-circuit protection | 15 A continuous |
| **RC snubber** (per MOSFET) | Damp V<sub>DS</sub> ringing | 22 Ω 2 W + 2.2 nF / 630 V across D-S |
| **Firmware UV** | DC bus undervoltage | 0.80 × VNOM (default 40 V at VNOM = 50) |
| **Firmware OV** | DC bus overvoltage | 1.16 × VNOM (default 58 V) |
| **Firmware OC** | Output overcurrent | Operator-set, default 15 A, range 0.5–20 A |
| **Firmware IMBAL** | DC bus imbalance | 0.20 × VNOM (default 10 V difference) |
| **Sensor-lost** | Required ADC stuck at rail | Auto-latched after 5 consecutive stuck reads |
| **N-of-M debounce** | Reject single-sample noise on every trip condition | 3 consecutive 1 kHz scans (3 ms) |
| **Hardware FAULT_OUT (PB5)** | External fault indicator / interlock | Active-LOW when any fault latched |
| **`BDTR.MOE = 0` on trip** | Master output disable | Drives all MOSFETs OFF via OSSI=1 |

The protection chain has both hardware and software layers, with **soft-thresholds that scale with VNOM** so the inverter can be bench-tested below the 50 V design point (e.g. at 12 V) without UV firing immediately. Details on the threshold derivation and the auto-mode-demotion behaviour are in [docs/firmware/protection](../firmware/protection.md).

### 3.5 PCB stack-up and layout

**4-layer FR-4 TG155**, 1.6 mm thick, 1 oz outer / 0.5 oz inner copper, HASL-with-lead surface finish, fabricated by JLCPCB. The 4-layer choice was driven by the iteration-3 grounding failure — see [iteration-3](../iteration-history/iteration-3.md) and [grounding-fix design note](../design-notes/grounding-fix.md). The inner layers carry **two separate ground pours**: 5V_GND on L2 (controller region only, isolated from the bridge regions) and 50V_GND on L3 (per-bridge pours, never connected to each other or to 5V_GND). The only paths between these grounds are the four isolation parts (TLP250, B0515S, 6N137 × 2). Stitched ground vias bind L1↔L2 in the controller region and L1↔L3 in each bridge region; no via crosses the isolation boundary.

The full stack-up specification + JLCPCB order checklist is at [`hardware/single-bridge-v4/stackup.md`](https://github.com/feaksel/chb-inverter/blob/main/hardware/single-bridge-v4/stackup.md).

---

## 4. Firmware design

### 4.1 Architecture

The firmware is **bare-metal CMSIS** with a thin HAL bring-up shim (retained from CubeMX so HAL_IncTick fires from SysTick). Runs on the STM32F303RE at **64 MHz** from HSI/2 × PLL — no external crystal required. Total Flash usage: 36 KB of 512 KB available. RAM: 4.1 KB of 64 KB. Zero warnings under `-Wall -Wextra -Wshadow -Wundef`. Source at [`firmware/stm32-f303re/`](https://github.com/feaksel/chb-inverter/tree/main/firmware/stm32-f303re/) in this repo (imported via `git subtree` with full upstream history).

The control flow:

1. **main()** initializes the system clock → SysTick @ 1 kHz → sine LUT (256 samples) → GPIO → TIM1 + TIM8 (with `BDTR.MOE = 0` at boot) → TIM6 → USART2 → NVIC → FSM.
2. **TIM1 update IRQ** (5 kHz with PSC, 500 Hz with STAIR) dispatches to the active modulator. The modulator owns all PWM duty-cycle writes (CCR1/CCR2 on TIM1 and TIM8).
3. **TIM6 IRQ** (1 kHz) sets `g_sense_pending`. The main loop calls `Sensing_Service()` for the blocking bit-banged SPI reads — keeps the bit-banger out of interrupt context where higher-priority IRQs would stretch the SCK timing.
4. **Main loop** runs `FSM_Run()` — handles UART commands, services sensing, runs protection, manages state transitions, emits the 20 Hz telemetry frame.

The decision to go bare-metal rather than HAL is documented in the firmware CHANGELOG: HAL adds layers of indirection that are awkward to reason about for a hard real-time control loop. The HAL is compiled but only `HAL_IncTick()` actually runs.

### 4.2 Finite state machine

```mermaid
stateDiagram-v2
    [*] --> BOOT
    BOOT --> IDLE: ADC self-test &<br/>pick best mode
    IDLE --> PRECHARGE: START
    IDLE --> FAULT: sensor fault
    PRECHARGE --> RUN: g_precharge_done
    PRECHARGE --> IDLE: STOP
    PRECHARGE --> FAULT: UV / OV / OC / IMBAL
    RUN --> IDLE: STOP
    RUN --> FAULT: UV / OV / OC / IMBAL
    FAULT --> IDLE: CLEAR (after condition cleared)
```

Five states, with the following per-state semantics:

| State | MOE | Behavior |
|---|---|---|
| **BOOT** | 0 | Hardware init, ADC self-test, sensing-mode auto-selection. Drops to IDLE. |
| **IDLE** | 0 | Both advanced-timer MOE bits low. Accepts all commands. |
| **PRECHARGE** | 1 | MOE on; PWM ISR forces all low-side MOSFETs ON for 6 ms (3 PWM periods at 500 Hz) to seed the bootstrap-style charge equilibrium. Drops to RUN when `g_precharge_done`. |
| **RUN** | 1 | PWM enabled. Protection runs after every 1 kHz sensor scan. |
| **FAULT** | 0 | MOE forced off via `BDTR.MOE = 0`; fault bits latched; `FAULT_OUT` pin pulled LOW. Operator must send `CLEAR` *after* the underlying condition is gone. |

The 3 ms (3-sample) N-of-M debounce on every fault trip rejects single-sample noise without significantly delaying the protection response. A manual operator-initiated trip (`TRIP` command, latches `FAULT_MANUAL = 0x20`) exercises the full fault path for demos even when no sensor is reading a real out-of-range value.

The **auto-start** path is layered on top: if no UART RX byte is received within 3 s of `FSM_Init()`, the FSM issues its own `START` with the loaded defaults and emits `$A,AUTO_START`. This makes the firmware usable in unattended-demo deployments (USB just powering the Nucleo, no PC). The dashboard's `SerialSource` transmits `STATUS` on connect and on every detected `BOOT_SELF_TEST_DONE`, which cancels auto-start whenever an operator is present — including across Nucleo resets.

### 4.3 Modulators — STAIR, PSC, STAIR_ALT

The firmware ships three modulators, selectable at runtime over UART:

| Modulator | Switching strategy | When to use |
|---|---|---|
| **STAIR** *(default boot)* | 500 Hz quantize-to-5-levels staircase; Bridge 1 carries the ±1 step | Known-good fallback; not real PWM, but immediately produces 5 distinct levels on scope |
| **PSC** *(as-built default after bench)* | Unipolar phase-shifted carrier SPWM; TIM8 CNT preset to PWM_PERIOD/2 for the 90° carrier shift | The project deliverable; bridges thermally balanced |
| **STAIR_ALT** | Same staircase output as STAIR, but the bridge carrying the ±1 step alternates | Hard-fallback if PSC's carrier shift cannot be made to work on a particular hardware revision |

The selection rationale — particularly the IPD-LS-PWM → PSC switch motivated by Bridge 1's thermal asymmetry — is in [psc-vs-lspwm](../design-notes/psc-vs-lspwm.md). The implementation gotcha for PSC is that the TIM8 ↔ TIM1 counter offset must hold at exactly ARR/2 (90° phase) or the cascade output degrades from 5-level back to 3-level. The firmware hardens this with three measures:

1. **TIM8 CNT is written after `CR1_CEN` is set**, so the post-`EGR_UG` update generation cannot clobber it.
2. **The actual measured offset is read back** and exposed as `g_pwm_measured_cnt_offset`.
3. **A boolean `lock`** is published: `OK` if the measured offset is within ±5 ticks of ARR/2, `BAD` otherwise. The `$C,...,cntoff=N,lock=OK|BAD` telemetry line reports both, so the operator can confirm the carrier phase is locked before arming the bridges.

A `BAD` lock at any time during operation lets the operator fall back to `STAIR_ALT` as a hard backup without losing 5-level output — STAIR_ALT always gives 5 distinct levels because it's static-level selection, not PWM modulation.

### 4.4 Sensing modes

The firmware supports six per-mode protection configurations, auto-selected at boot based on which MCP3201 channels are responsive:

| ID | Mode | Sensors | Active protection |
|---:|---|---|---|
| 0 | `FULL` | DC1, DC2, current | UV, OV, OC, IMBAL |
| 1 | `DC_ONLY` | DC1, DC2 | UV, OV, IMBAL |
| 2 | `CUR_ONLY` | Current | OC |
| 3 | `OPEN` | None | **None** — emits a UART warning when selected or started |
| 4 | `DC1` | DC1 (+ optional current) | DC1 UV/OV + OC if available |
| 5 | `DC2` | DC2 (+ optional current) | DC2 UV/OV + OC if available |

At boot, each ADC is read four times. Channels stuck at `0x000` or `0xFFF` are marked unavailable; the FSM auto-demotes to the most capable supported mode and emits `$E,MODE_DEMOTED`. `OPEN` mode is allowed (for hardware where sensors aren't yet wired) but emits `$E,WARNING_OPEN_LOOP_NO_PROTECTION` whenever it is selected or started — this is the standalone-demo path, and the warning is a warning rather than a block because the operator who deployed in `OPEN` mode accepted the risk.

### 4.5 UART protocol — operator commands and telemetry

Line-based, 115200 8N1, terminated by `\n` or `\r\n`. Command echoes return `$A,<cmd>\r\n`; rejections return `$E,<reason>\r\n`. Telemetry at 20 Hz:

```text
$T,<ms>,<state>,<mode>,<fault>,<vdc1>,<vdc2>,<iout>,<level>*<chk>\r\n
```

`<chk>` is the 8-bit XOR of bytes between `$` and `*`, hex. Fault bits: `0x01 = UV`, `0x02 = OV`, `0x04 = OC`, `0x08 = IMBAL`, `0x10 = SENSOR_LOST`, `0x20 = MANUAL`. Unavailable channels print `NAN`.

The full command set, line-prefix legend, and configuration-line formats are at [docs/firmware/uart-protocol](../firmware/uart-protocol.md). The NMEA-style format was chosen for parser portability (any language can read it), terminal-friendliness during bring-up (human-readable on a serial monitor), and robustness against half-typed commands.

### 4.6 The PySide6 operator dashboard

The dashboard at [`firmware/stm32-f303re/dashboard/`](https://github.com/feaksel/chb-inverter/tree/main/firmware/stm32-f303re/dashboard) provides:

- **Live monitoring** of the existing USART2 telemetry (20 Hz).
- **A PC-only simulator** with 8 pre-baked scenarios (nominal, UV, OV, OC, IMBAL, sensor-lost, open-loop, mode demotion) for fault demos that never touch hardware.
- **Operator controls** — every firmware command, gated behind an `Arm live START` checkbox for commands that would energize the bridges.
- **Sensor graphing** with auto-follow + manual zoom.
- **Modulation + output visual twin** — the carrier-vs-reference comparison + the reconstructed 5-level output step view.

The safety model: simulator scenarios and live-serial commands are mutually exclusive (scenarios disable when live is armed). The serial source transmits `STATUS` on connect and on every detected `$A,BOOT_SELF_TEST_DONE` so that the firmware's 3 s auto-start path is **always cancelled** when a dashboard is connected — including across Nucleo resets. This was a deliberate design point: a fault-demo button that accidentally tripped a real power stage would defeat the purpose of having a dashboard.

Unit tests for the parser and the simulator (40+ tests) are pure Python with no Qt dependency, so they run headless in CI. The `dashboard-tests` GitHub Actions workflow runs them on every push that touches the dashboard tree.

---

## 5. Iteration history

The hardware converged to the as-built design over four iterations. The per-iteration narrative — what was attempted, what failed, what was learned, what changed for next round — is in [docs/iteration-history](../iteration-history/index.md); the summary below distils what each iteration contributed to the final design.

### 5.1 Iteration 1 — single dual-bridge PCB, IRFZ44N, IPD LS-PWM

The first board hosted **both H-bridges on a single PCB** with IRFZ44N MOSFETs (per Build Guide v3.1 BOM), TLP250 gate drivers, and IPD level-shifted carrier PWM at 500 Hz. It worked — the firmware drove all eight gates, the sensing returned plausible values, and the cascade produced something that looked like 5 levels. But three problems surfaced under load:

- **V<sub>DSS</sub> headroom too tight.** A 55 V part on a 50 V bus has marginal headroom that gate-loop parasitics easily exceed.
- **TVS / MOSFET-V<sub>DSS</sub> mismatch.** The 1.5KE62A TVS clamps at 84.5 V — above the IRFZ44N V<sub>DSS</sub>. A TVS event would still kill the MOSFETs. Latent BOM hazard.
- **Bridge-1 thermal asymmetry.** IPD level-shifted PWM maps Bridge 1 to the inner-band switching: Bridge 1's MOSFETs ran measurably hotter than Bridge 2's. The asymmetry is intrinsic to IPD and would have needed an active bridge-swap each fundamental cycle to even out.

None of these were show-stoppers for a one-off bench session, but together they made iteration 1 a poor production candidate.

### 5.2 Iteration 2 — gate-drive routing rework, bootstrap lessons

Iteration 2 kept the iteration-1 architecture (single dual-bridge PCB, IRFZ44N, IPD) and reworked the **gate-drive routing**: shorter trace lengths, better decoupling on TLP250 V<sub>CC</sub>, bootstrap-related components repositioned closer to the MOSFET sources. The bring-up surfaced a **bootstrap timing issue** that hadn't shown up in iteration 1 — at modulation indices above 0.9, the bootstrap cap sagged over consecutive cycles, the high-side gate voltage dropped below threshold, and the leg failed to turn on cleanly.

This iteration's contribution to the final design was conceptual: it forced the team to recognize that **bootstrap drive is fundamentally incompatible with cascaded floating bridges** — Bridge 2's V<sub>S</sub> never returns to ground, so the bootstrap diode never refreshes the cap. That recognition is what drove the iteration-3 commitment to per-bridge isolated 15 V supply (B0515S DC-DC) rather than relying on bootstrap.

Two firmware changes also landed in this iteration: the **95 % high-duty clamp** (to guarantee a minimum LS-on window each cycle for any bootstrap-style refresh) and the **6 ms PRECHARGE state** before any RUN transition.

### 5.3 Iteration 3 — per-bridge isolation, MISO topology surprise, errata

Iteration 3 was the first board to implement the full per-bridge isolation architecture: B0515S DC-DC per bridge, 6N137 optocouplers on every SPI line, 78L05 deriving the 5 V island-side logic supply from the local 15 V rail. This is the architecture that survives into iteration 4.

Three problems surfaced during bring-up that drove the iteration-4 re-architecture:

**The 5V_GND ↔ 50V_GND coupling problem.** The board had inadvertent coupling between the controller's 5V_GND and the bridges' 50V_GND through (a) a continuous inner-plane ground pour that bridged the isolation boundary and (b) marginal copper creepage on the optocoupler footprints. Symptoms: intermittent `SENSOR_LOST` events under load, garbage `STATUS` values when Bridge 2 was switching at the cascade peak, occasional protection-trip glitches during clean-load runs — all classical signs of broken isolation. The full reconstruction and the iteration-4 fix is in [grounding-fix design note](../design-notes/grounding-fix.md).

**MISO topology surprise.** The firmware had been written assuming **three independent MISO lines** (one per MCP3201). The iteration-3 board surfaced the reality: the upper-bridge island has only **two** MISO returns, with DC2 and current sharing one (PC3). The firmware was rewritten — the `pwm-rewrite-configurable` branch — to perform strictly sequential one-channel-per-CS reads. This was the right call: respinning the board would have cost weeks, while rewriting the firmware took an afternoon.

**Pin-mismatch errata.** The build-guide v3.1 PDF had two MCP3201 / 78L05 pin errors and a PWM_1L pin error (PA10 listed; actual board uses PA12). The schematic was right; the documentation was wrong. Build Guide v4.0 corrects all three; this is the team's "documentation can lie, schematic is source-of-truth" lesson made concrete.

### 5.4 Iteration 4 — the as-built

Iteration 4 was a **re-architecture from iteration-3 lessons**, not a tweak. Six structural changes:

| Change | From | To | Why |
|---|---|---|---|
| Board topology | Single dual-bridge PCB | **Two identical single-bridge PCB modules** | Modularity; interchangeable; one fab order |
| Stack-up | 2-layer | **4-layer, 1.6 mm FR-4, JLCPCB** | Dedicated separated ground planes solve the iteration-3 coupling |
| Power MOSFET | IRFZ44N (55 V) | **IRFB4110 (100 V, 4.5 mΩ)** | V<sub>DSS</sub> headroom; fixes TVS-clamp mismatch |
| Modulator | IPD LS-PWM at 500 Hz | **PSC-PWM at 5 kHz** | Bridge symmetry; better filter behaviour; lower THD |
| Dead time | 2 µs (IRFZ44N) | **3 µs (BDTR.DTG = 0xA0)** | Compensates IRFB4110's ~2× gate charge |
| MISO topology | 3-independent assumption | **2 MISO lines (1 lower + 1 shared upper)** | Matches as-fabricated routing |

The bench validation confirmed every headline goal: 5 distinct cascade levels on scope at 100 V, PSC `lock=OK` reported consistently, both bridges thermally matched within ≈ 3 °C, no false `SENSOR_LOST` events across multi-minute runs, dashboard auto-cancel of firmware auto-start working as designed. The full iteration-4 narrative is at [iteration-4](../iteration-history/iteration-4.md).

---

## 6. Bring-up and test results

### 6.1 Bring-up procedure

The bring-up procedure for this hardware + firmware combination is documented in two complementary references that both ship in the firmware repository:

- **[FIRST_BENCH_SESSION.md](../bringup/first-session.md)** — single-session linear walkthrough with explicit pass/fail checkpoints. Folds together Step 0 + Phases 2–7b + Phase 8 of the comprehensive reference and adds TLP250-protection checks at every step. Start here the first time a board is on the bench.
- **[HARDWARE_BRINGUP.md](../bringup/reference.md)** — comprehensive phase-by-phase reference. Covers every test phase with what the firmware emits on UART, what the scope should show, and the troubleshooting trees for when reality diverges.

The standard sequence: boot the firmware → confirm `BOOT_SELF_TEST_DONE` + `$C` config line on UART → configure modulator (`MOD PSC`, `FSW 5000`, `BRIDGE BOTH`) → confirm `lock=OK` → bring up DC supplies one at a time → arm live → `START` → verify 5-level cascade on scope. At any sign of trouble, the dashboard's `FORCE FAULT` button or the UART `TRIP` command exercises the full fault path without needing a real out-of-range sensor reading.

### 6.2 Bench-validated results

| Metric | Result | Source |
|---|---|---|
| Cascade output levels (no filter) | **5 distinct** | scope capture in [populated-photos](../hardware/populated-photos.md) |
| Cascade output voltage | **100 V peak** | bench supplies at 50 V per bridge |
| Switching frequency | 5 kHz (PSC) | per-modulator selectable |
| Fundamental | 50 Hz | runtime-tunable 10–400 Hz |
| PSC carrier phase lock | `lock=OK` consistent | `$C,...,cntoff,lock` line |
| Inter-bridge thermal delta | **≈ 3 °C** under sustained run | MOSFET case-temperature touch-check |
| False `SENSOR_LOST` events | **0** over multi-minute runs | `$F` line absent in capture |
| Auto-start cancellation | working, including across resets | `STATUS (auto-cancel post-reset)` events |
| Firmware Flash usage | 36 KB / 512 KB | post-link size report |
| Firmware RAM usage | 4.1 KB / 64 KB | post-link size report |
| Compile warnings | 0 under `-Wall -Wextra -Wshadow -Wundef` | bench-PC build |

### 6.3 Per-modulator bench comparison

| Modulator | Distinct cascade levels | Bridge balance | Output ripple |
|---|---|---|---|
| **STAIR** | 5 (static level selection) | Asymmetric — Bridge 1 hotter | At fundamental frequency only |
| **STAIR_ALT** | 5 | Symmetric (alternates which bridge carries ±1) | At fundamental frequency only |
| **PSC** | 5 | **Symmetric — bridges matched ~3 °C** | At 2× f<sub>sw</sub> (10 kHz) — easier to filter downstream |

The team verified all three in the same session. PSC was the deliverable; STAIR was the fallback for when PSC `lock=BAD` (which did not happen in the bench session); STAIR_ALT was the additional fallback for when PSC fundamentally would not lock on a different board revision.

### 6.4 The 100 V output capture

The headline scope capture — **five distinct cascade output levels at 100 V output under sustained PSC-PWM**, no filter — is the project deliverable. It satisfies the graduation spec stated at the 23 October 2025 project meeting:

> "100 V tek giriş bölünerek 2 50 V olacak şekilde çıktı 100 V olacak yani."  
> *("100 V single input split into two 50 V supplies; cascade output reaches 100 V.")*

The capture is at [populated-photos → Headline](../hardware/populated-photos.md#headline--100-v-output-5-distinct-cascade-levels).

### 6.5 What was not measured

The team did **not** measure THD on the bench. The Simulink prediction was 4.9 % pre-filter; an FFT capture from a bench session at the same operating point would confirm or refine that number. Adding this is on the roadmap. Other deferred bench measurements: dead-time-edge scope captures (rising/falling close-ups), per-MOSFET thermal-scan photos under sustained load, and per-bridge current-balance plots. Tracker artifact #8 enumerates them.

---

## 7. Lessons learned

Five themes recurred across the four iterations and the firmware bring-up. They are written here as advice for whoever picks the project up next.

### 7.1 Topology imposes hardware requirements that aren't optional

CHB topology **requires** galvanic isolation between every floating bridge and the controller. This is not a preference, not a "for noise immunity", not a "good engineering practice" — it's a structural consequence of the cascaded series-connection. Bootstrap-based gate drivers (IR2110) **fundamentally cannot** drive a non-ground-referenced bridge. The Simulink simulation that confirmed this — with the IR2110 behavioural model collapsing on the upper bridge — was the deciding evidence before any silicon was committed. Picking the right gate-drive part (TLP250 optical + B0515S isolated supply) at the start saved a wasted board iteration.

### 7.2 Component substitutions need the firmware + protection chain updated together

The IRFZ44N → IRFB4110 swap was three coupled changes, not one. **MOSFET part** swap. **Dead time** raised in firmware (2 µs → 3 µs) to compensate for the higher gate charge. **TVS / V<sub>DSS</sub> check** confirmed the protection chain actually protects (84.5 V clamp now sits below 100 V V<sub>DSS</sub>). Treating the MOSFET swap as a single-line BOM edit would have left a latent defect (TVS clamp above MOSFET breakdown). The lesson: every component substitution needs a checklist that traces through firmware constants and protection-chain assumptions.

### 7.3 Defensive instrumentation pays off

The PSC carrier-shift `lock=OK|BAD` diagnostic was added defensively before the first bench session, on the theory that "if it's wrong, we want to know without scope-debugging". It caught a real problem on iteration-4 day one — the post-`EGR_UG` sequence was clobbering `TIM8->CNT`, dropping PSC to 3-level output. The fix (write TIM8 CNT after `CR1_CEN` is set) was straightforward once the symptom was visible. Without the diagnostic, the team would have spent an afternoon scoping carrier alignments. **Cheap instrumentation, large dividend.**

### 7.4 Build guide is documentation; schematic is source of truth

The v3.1 build-guide PDF had three pin-assignment errors (PWM_1L, MCP3201 pins 5/7, 78L05 pins 1/3) that the project survived only because the schematic was authored against the actual datasheets. When documentation disagrees with what gets fabricated, **what gets fabricated wins**. Build Guide v4.0 carries all three corrections; the iteration-3 KiCad backup is preserved in the repo for context.

### 7.5 Simulation kills bad design paths cheaply

The IR2110 incompatibility with CHB topology was identified in Simulink before any board was built — the simulated IR2110 gate driver collapsed to < 5 V on Bridge 2 because of the floating-reference issue. The team committed to TLP250 + isolated DC-DC instead, and never produced a board with bootstrap drive on the upper cell. A wasted iteration would have cost ~3 weeks (PCB design + fab + assembly + bring-up). The Simulink work cost ~3 days. **The leverage ratio for design-phase simulation is enormous when it kills an architectural mistake.**

---

## 8. Future work / product roadmap

The roadmap in [docs/roadmap](../roadmap/index.md) enumerates six tracks for extending the as-built bench prototype. In order of engineering cost (cheapest first):

| Track | Engineer-months | What it unlocks |
|---|---:|---|
| [PSC tuning](../roadmap/ps-pwm-tuning.md) | 0.5 | Sweep f<sub>sw</sub> + carrier phase; add closed-loop carrier-lock |
| [LC output filter](../roadmap/lc-filter.md) | 1 | Drive non-trivial loads (transformer, RL, motor) without injecting cascade-step harmonics |
| [Closed-loop control](../roadmap/closed-loop-control.md) | 2 | Output-voltage regulation against load + bus drift (currently open-loop) |
| [Thermal enclosure](../roadmap/thermal-enclosure.md) | 2 | Move from open-bench to enclosed deployment (forced air + EMI filtering) |
| [Grid tie](../roadmap/grid-tie.md) | 4–6 | PLL + anti-islanding + compliance testing — the hardest single track |
| [Product path](../roadmap/product-path.md) | 6–9 | All of the above plus dashboard productisation + compliance certification + manual |

The [experimental](https://github.com/feaksel/chb-inverter/tree/main/experimental) tracks (custom RV32IM SoC with PWM accelerator, FPGA controller) are intentionally **not** on this roadmap — they have no validated path to the as-built hardware. The RISC-V SoC went through a full Cadence Genus → Innovus → GDSII flow against the SkyWater 130 nm PDK as an exploratory parallel project, and is preserved in the repo for continuity, but it would need at minimum FPGA equivalence validation and a level-shifter board to interface with the existing TLP250 gate-drive chain before it could replace the STM32.

---

## 9. References

The references below extend the ELE 401 interim report bibliography with project-specific datasheets and standards. The bibliography itself is preserved verbatim in [`docs/assets/pdfs/ELE401_Fall2025_IR.pdf`](https://github.com/feaksel/chb-inverter/blob/main/docs/assets/pdfs/ELE401_Fall2025_IR.pdf).

### Multilevel inverter literature

- Rodriguez, J., Lai, J. S., & Peng, F. Z. (2002). *Multilevel inverters: a survey of topologies, controls, and applications.* IEEE Transactions on Industrial Electronics, 49(4), 724–738.
- Kouro, S. et al. (2010). *Recent advances and industrial applications of multilevel converters.* IEEE Transactions on Industrial Electronics, 57(8), 2553–2580.
- McGrath, B. P., & Holmes, D. G. (2002). *Multicarrier PWM strategies for multilevel inverters.* IEEE Transactions on Industrial Electronics, 49(4), 858–867.
- Holmes, D. G., & Lipo, T. A. (2003). *Pulse Width Modulation for Power Converters: Principles and Practice.* Wiley-IEEE Press.
- Corzine, K. A., & Familiant, Y. L. (2002). *A new cascaded multilevel H-bridge drive.* IEEE Transactions on Power Electronics, 17(1), 125–131.
- Malinowski, M. et al. (2010). *A survey on cascaded multilevel inverters.* IEEE Transactions on Industrial Electronics, 57(7), 2197–2206.

### Standards

- IEEE 519-2022, *Recommended Practice and Requirements for Harmonic Control in Electric Power Systems.*
- IEEE 1547-2018, *Standard for Interconnection and Interoperability of Distributed Energy Resources with Associated Electric Power Systems Interfaces.*
- IEC 61000-4-7:2002, *Electromagnetic compatibility — General guide on harmonics and interharmonics measurements.*
- IEC 62109-1 / -2, *Safety of power converters for use in photovoltaic power systems.*

### Datasheets (referenced, not redistributed)

- STMicroelectronics, *STM32F303RE Reference Manual* (RM0316).
- Infineon, *IRFB4110 N-channel HEXFET datasheet.*
- Toshiba, *TLP250H Photocoupler datasheet* — [PDF in repo](https://github.com/feaksel/chb-inverter/blob/main/docs/assets/pdfs/tlp250-datasheet.pdf).
- Microchip, *MCP3201 12-bit A/D Converter datasheet.*
- Allegro, *ACS712 Hall-effect Current Sensor datasheet.*
- Onsemi, *6N137 High Speed Optocoupler datasheet.*
- Mornsun, *B0515S-1WR3 Isolated DC-DC datasheet.*

### Project-internal references

- *CHB Inverter Build Guide v4.0* (May 2026) — [`docs/hardware/build-guide-v4.md`](../hardware/build-guide-v4.md). Canonical engineering reference.
- *CHB Inverter Build Guide v3.1* (February 2026) — [`docs/assets/pdfs/CHB_Inverter_Build_Guide_v3_1.docx`](https://github.com/feaksel/chb-inverter/blob/main/docs/assets/pdfs/CHB_Inverter_Build_Guide_v3_1.docx). Preserved for iteration history; carries the errata that v4 corrects.
- *ELE 401 Fall 2025 Interim Report* — [`docs/assets/pdfs/ELE401_Fall2025_IR.pdf`](https://github.com/feaksel/chb-inverter/blob/main/docs/assets/pdfs/ELE401_Fall2025_IR.pdf).
- *ELE 402 Spring 2026 Interim Report v4* — [`docs/assets/pdfs/ELE402_Spring2026_IR_v4.pdf`](https://github.com/feaksel/chb-inverter/blob/main/docs/assets/pdfs/ELE402_Spring2026_IR_v4.pdf).
- Firmware *CHANGELOG.md* — [`firmware/stm32-f303re/CHANGELOG.md`](https://github.com/feaksel/chb-inverter/blob/main/firmware/stm32-f303re/CHANGELOG.md). Per-release design-decision narrative.
- *FIRST_BENCH_SESSION.md*, *HARDWARE_BRINGUP.md*, *FSM_NOTES.md* — in the firmware tree; also rendered into the docs site under [bring-up](../bringup/index.md).

---

## 10. Appendices

### Appendix A — Full bill of materials

The canonical BOM is at [`hardware/single-bridge-v4/bom.csv`](https://github.com/feaksel/chb-inverter/blob/main/hardware/single-bridge-v4/bom.csv) (GitHub renders CSV as a sortable table). The source spreadsheet (`bom-source-v3_2.xlsx`) is preserved alongside for traceability.

| Category | Lines | Need qty | Subtotal (TL) |
|---|---:|---:|---:|
| A. Power semiconductors | 6 | 28 | 1 151.6 |
| B. Sensing ICs | 4 | 12 | 539.0 |
| C. DC-bus bulk + protection | 3 | 5 | 86.0 |
| D. Gate-drive passives | 4 | 60 | 24.0 |
| E. Bootstrap | 1 | 4 | 6.0 |
| F. Snubber | 2 | 16 | 36.0 |
| G. Isolated-supply passives | 2 | 6 | 3.2 |
| H. DC-bus sensing passives | 5 | 13 | 5.8 |
| I. Current-sense passives | 2 | 2 | 0.6 |
| J. Connectors + mechanical | 5 | 35 | 132.5 |
| **Project total** | **34** | **181** | **≈ 1 985 TL** |

Suppliers are restricted to Turkish domestic vendors: Motorobit, Direnc.net, Robotistan. The IRFZ44N → IRFB4110 substitution (line A.1) is documented in [bom.md](../hardware/bom.md).

### Appendix B — Pin map (STM32 Nucleo-F303RE)

Full pin map (with v3.1 errata noted) is at [`docs/firmware/pin-map.md`](../firmware/pin-map.md). The PWM and sensing signals:

| Signal | Function | Pin | Notes |
|---|---|---:|---|
| PWM_1H | TIM1_CH1 | PA8 | Bridge 1 high-side leg A |
| PWM_1L | TIM1_CH1N | PA7 | Bridge 1 low-side leg A |
| PWM_2H | TIM1_CH2 | PA9 | Bridge 1 high-side leg B |
| PWM_2L | TIM1_CH2N | **PA12** | Bridge 1 low-side leg B *(v3.1 erroneously listed PA10)* |
| PWM_3H | TIM8_CH1 | PB6 | Bridge 2 high-side leg A |
| PWM_3L | TIM8_CH1N | PB3 | Bridge 2 low-side leg A |
| PWM_4H | TIM8_CH2 | PB8 | Bridge 2 high-side leg B |
| PWM_4L | TIM8_CH2N | PB0 | Bridge 2 low-side leg B |
| SCK | Bit-banged MCP3201 SCK | PA5 | Shared, ~140 kHz |
| CS_DC1 / DC2 / CUR | MCP3201 chip selects | PC0 / PC1 / PC2 | One per channel |
| MISO_DC1 | Lower island MISO | PA6 | Dedicated |
| MISO_DC2 / CUR | Upper island MISO | PC3 | **Shared** between DC2 + current ADCs |
| USART2_TX / RX | ST-LINK VCP | PA2 / PA3 | 115200 8N1 |
| FAULT_OUT | Active-LOW fault indicator | PB5 | Drives external interlock |

### Appendix C — Key firmware code listings

The firmware source is at [`firmware/stm32-f303re/`](https://github.com/feaksel/chb-inverter/tree/main/firmware/stm32-f303re/). The three structurally-important blocks:

- **FSM transition table**: [`Core/Src/fsm.c`](https://github.com/feaksel/chb-inverter/blob/main/firmware/stm32-f303re/Core/Src/fsm.c) — `FSM_Run()` is the supervisory loop; per-state behaviour is in `handle_<state>()` helpers.
- **PSC modulator + lock diagnostic**: [`Core/Src/pwm_modulator.c`](https://github.com/feaksel/chb-inverter/blob/main/firmware/stm32-f303re/Core/Src/pwm_modulator.c) — `psc_modulate()` runs in the TIM1 update IRQ; `timer_apply_period_and_phase()` writes TIM8 CNT after `CR1_CEN` is set and exposes `g_pwm_measured_cnt_offset` + `g_pwm_phase_locked`.
- **SPIINV mask + sequential MCP3201 read**: [`Core/Src/spi_mcp3201.c`](https://github.com/feaksel/chb-inverter/blob/main/firmware/stm32-f303re/Core/Src/spi_mcp3201.c) — `SPI_MCP3201_Read()` reads exactly one channel per CS assertion; `SPI_MCP3201_SetInvert()` adjusts per-line polarity at runtime.

### Appendix D — IEEE 519-2022 compliance

| Requirement | Limit | Project target | Status |
|---|---|---|---|
| Voltage THD (V < 1 kV) | ≤ 8 % | < 5 % | **Simulink prediction 4.9 %** — bench FFT pending |
| Measurement methodology | IEC 61000-4-7 (10/12 cycle windows) | Same | Not yet measured |
| Individual harmonic limits | Per Table 1 | Same | Inherited from THD target |

### Appendix E — Sustainable Development Goals alignment

Three SDGs map directly to this project (from the ELE 401 Appendix B):

- **SDG 7: Affordable and Clean Energy.** CHB topology accommodates multiple DC sources naturally (PV strings, battery packs). > 95 % efficiency target. Modular structure scales residential → industrial.
- **SDG 9: Industry, Innovation and Infrastructure.** Advances multilevel-inverter control. Modern embedded control (STM32). Exploration of custom-silicon controllers (the experimental RISC-V track). Educational value for future power-electronics engineers.
- **SDG 13: Climate Action.** Enables renewable-energy integration. Reduces reliance on fossil-fuel generation. High efficiency reduces energy waste.

### Appendix F — File map of this repository

| Path | What it is |
|---|---|
| `docs/` | MkDocs Material source — every .md becomes a published page on https://feaksel.github.io/chb-inverter/ |
| `hardware/single-bridge-v4/` | KiCad project, gerbers, BOM CSV, populated photos for the as-built board |
| `hardware/legacy/iteration-3/` | KiCad zip backup of iteration 3 + v3.1 BOM |
| `firmware/stm32-f303re/` | STM32 source (git subtree from the firmware repo, full upstream history) + PySide6 dashboard |
| `simulation/simulink/` | Three Simulink models — v1 IPD baseline, v2 gate-driver sweep, v3 RL load + LC filter |
| `experimental/risc-v-soc/` | Custom RV32IM SoC — RTL, GDSII, layout renders, synthesis scripts. **Not part of graduation deliverable.** |
| `tools/` | BOM validator, docs link checker, PCB renderer |
| `_AGENT_TRACKER.md` | Status of every external artifact this project needed (mostly ✅ now) |
| `_AGENT_HANDOVER.md` | Maintenance + extension instructions (see Phase 8 handover) |

---

*End of consolidated graduation report. For corrections, errata, or questions, see [About → Team](../about/team.md) for contact details.*

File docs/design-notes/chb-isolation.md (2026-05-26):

---
title: CHB isolation
---

# CHB isolation

> **Single-sentence summary.** Cascaded H-Bridge topology imposes an **absolute** requirement for galvanic isolation between each bridge and the controller, because every bridge above the ground-referenced cell sits at a floating potential that swings with the cascade-output. Anything that touches both sides without isolation will eventually let the floating side damage the controller side.

## What "floating" means in CHB

In a 5-level CHB with two cells:

- **Bridge 1** (lower cell): its low-side rail is the system ground reference. V<sub>S</sub> of its HS MOSFETs only swings between 0 and +V<sub>DC1</sub>.
- **Bridge 2** (upper cell): its low-side rail is **not** ground — it's the output node of Bridge 1, which itself swings between -V<sub>DC1</sub> and +V<sub>DC1</sub>. So Bridge 2's "ground" floats between -V<sub>DC1</sub> and +V<sub>DC1</sub>, and Bridge 2's HS source rides on top of that with another ±V<sub>DC2</sub> of swing.

At V<sub>DC1</sub> = V<sub>DC2</sub> = 50 V, the floating ground of Bridge 2 can be anywhere from -50 V to +50 V relative to controller ground. The HS source of Bridge 2 can be at +100 V relative to controller ground at the positive cascade peak.

This is not a tolerance issue. It's not noise. It's the **defined behavior** of the topology. Any approach to driving or sensing Bridge 2 that doesn't account for it will fail.

## What breaks without isolation

The first instinct — share a common 15 V V<sub>CC</sub>, run the gate signal directly from the STM32 to the IR2110 inputs, share the SPI bus for the MCP3201 ADC — fails in three distinct ways. The team simulated each and confirmed.

### 1. Bootstrap drivers can't supply gate voltage

The IR2110 (and any bootstrap-based driver) has its **COM** pin connected to V<sub>S</sub> of the HS MOSFET. On Bridge 2, that COM pin floats at the cascade voltage minus the bridge voltage. The driver chip's internal logic now references a voltage that can swing 100 V at the PWM rate. The result:

- The bootstrap cap path through the IR2110 internal structure can't tolerate the common-mode swing.
- Even if it could, the bootstrap diode reverse-biases on every cycle when V<sub>S</sub> rises — the cap never refreshes.
- The driver's input logic, referenced to COM, sees the controller-side PWM signal at -50 V to +50 V common mode. Latch-up or destruction is the typical outcome.

Simulink validation (per the ELE 401 interim report §4.4) showed gate drive voltage dropping to < 5 V on Bridge 2 with IR2110 — MOSFETs never fully turn on. **This was the deciding evidence** that the IR2110 path could not be made to work and the project had to commit to optical isolation.

<figure markdown="span">
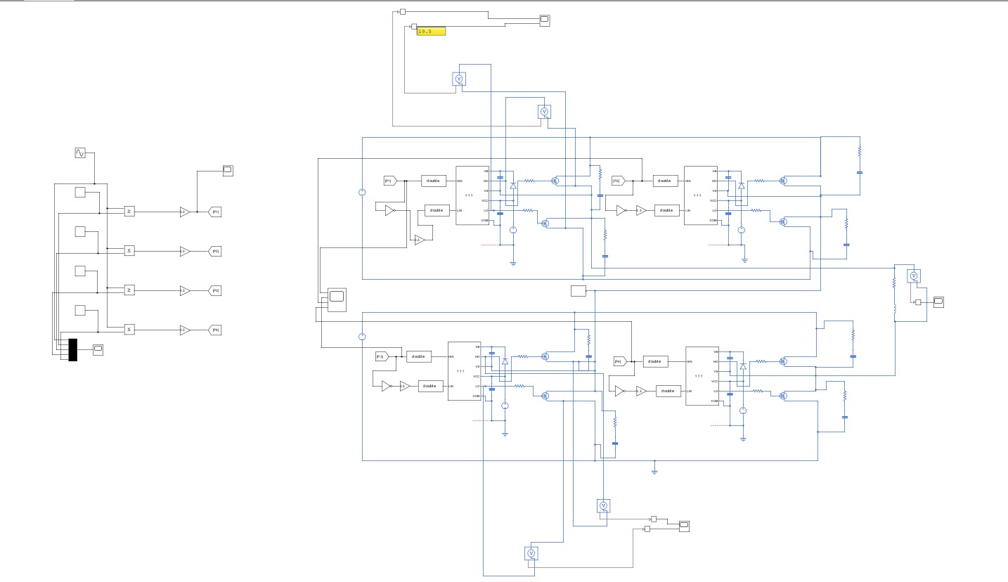
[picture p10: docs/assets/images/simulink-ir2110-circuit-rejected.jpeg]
Simulink — IR2110 circuit, evaluated and rejected for CHB
  
  <figcaption>The IR2110 simulation that killed the bootstrap path for CHB — Simulink behavioural model of the IR2110 driving an upper-bridge MOSFET. The bootstrap cap reverse-biases under the cascade's floating reference; gate drive collapses below threshold. The team committed to TLP250 + B0515S after this simulation.</figcaption>
</figure>

### 2. Common-mode coupling destroys the controller

Even if the gate driver problem were somehow solved (it can't be, but suppose), the SHARED 15 V supply between Bridge 2 and the controller is a common-mode path. When Bridge 2 swings its floating ground by 50 V at 5 kHz, that same V is impressed on the controller's V<sub>CC</sub> — at high di/dt through the parasitic capacitance of the shared supply.

The STM32 sees this as massive ground noise. ADC readings are garbage. UART corrupts. Eventually a transient exceeds the GPIO clamp and a pin is destroyed.

### 3. Sensing can't read the floating side

The MCP3201 on the floating bridge needs to measure voltages relative to that bridge's ground (so it can read the local DC bus). If you connect its SPI back to the controller without isolation, you're connecting controller ground to bridge ground — instantly defeating the isolation that the gate drivers also need.

## How the as-built handles it

The single-bridge v4 design implements isolation at **every** interface that crosses from the floating bridge to the controller:

```mermaid
flowchart LR
    subgraph Controller[Controller side — referenced to 5V_GND]
      MCU[STM32 F303RE]
      Sup5V[5 V from USB / VCP]
    end

    subgraph Bridge[Bridge side — floating at cascade voltage]
      MOS[IRFB4110<br/>×4 H-bridge]
      DCBus[DC bus ADC<br/>MCP3201]
      CurADC[Current ADC<br/>MCP3201]
      DCDC[B0515S<br/>5V → 15V isolated]
      TLP[TLP250 ×4<br/>gate drivers]
    end

    Sup5V -->|"isolated DC-DC"| DCDC
    DCDC --> TLP
    DCDC --> DCBus
    DCDC --> CurADC

    MCU -->|"PWM through<br/>TLP250 LED"| TLP
    TLP -->|"opto isolation"| MOS

    DCBus -->|"SPI via 6N137<br/>opto"| MCU
    CurADC -->|"SPI via 6N137<br/>opto"| MCU
```

Four isolation barriers:

| Barrier | Component | Spec |
|---|---|---|
| Gate drive | TLP250 optical | 2.5 kV galvanic, LED → photodetector + MOSFET output |
| Gate supply | B0515S DC-DC | 1 W, 4.5–5.5 V → 15 V, ≥ 3 kV isolation per part |
| ADC clock + chip-select | 6N137 optocoupler | 10 Mbit/s, separate one per signal |
| ADC data return | 6N137 optocoupler | Same — independent line for the MISO |

The two grounds (**5V_GND** on the controller side, **50V_GND** on the bridge side) are connected **only** through these isolation parts. Nothing else — no shared trace, no shared via, no shared cable shield — bridges the two grounds.

When that rule is violated, the symptoms are the [grounding-fix](grounding-fix.md) story — iteration 3 hit exactly that failure.

## Per-bridge isolation, not per-cell isolation

A subtle point: even **Bridge 1** (the ground-referenced one) is fully isolated from the controller in the as-built design. This is over-engineering relative to the strict topology requirement, but it's the right choice:

- The two PCB modules are **identical** — same layout, same parts, same isolation. Operating only one of them isolated and the other not would mean two different boards in stock, two different fab orders, and two different bring-up procedures.
- During bench bring-up, only one bridge is energized at a time. With both isolated, either can be the bench-test bridge without rewiring.
- For a future product, modularity matters more than the BOM saving from skipping the isolation parts on Bridge 1.

The cost: ~50 TL of extra DC-DC + optocouplers per module on the lower-bridge instance. Worth it.

## What to remember

- Isolation is a **topology requirement**, not a design preference.
- The IR2110 cannot drive a floating bridge. This was simulation-validated before any silicon was committed.
- Optical isolation (TLP250 for gates, 6N137 for SPI) + isolated DC-DC (B0515S) is the standard solution.
- Both modules use identical isolation so the modules are interchangeable.

Related: [Bootstrap fundamentals](bootstrap-fundamentals.md), [Grounding fix](grounding-fix.md), [Build Guide v4 §3 Isolation architecture](../hardware/build-guide-v4.md).

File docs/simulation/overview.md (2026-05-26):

# Simulation overview

The Simulink work was a **design-time aid** — it informed the topology, modulation, and gate-drive choices before any silicon was committed. It was not a live model and is not part of the runtime control loop.

## Headline results

| Metric | Value | Source |
|---|---|---|
| Predicted THD (pre-filter, LS-PWM) | **4.9 %** | LS-PWM model output, validated against the IEEE 519-2022 < 8 % limit |
| Predicted efficiency | > 95 % | Pre-filter, ideal switches, design-target load (≈ 400 W) |
| Predicted gate-drive failure mode | IR2110 floating reference | The simulation that killed the IR2110 path and forced the TLP250 choice |

## What was simulated

Three Simulink models are kept in `simulation/simulink/`:

| Model | What it covers |
|---|---|
| [`chb-5level-v1.slx`](https://github.com/feaksel/chb-inverter/blob/main/simulation/simulink/chb-5level-v1.slx) | First-pass 5-level CHB with IPD LS-PWM, ideal switches, resistive load. The model that produced the 4.9 % THD figure. |
| [`chb-5level-v2.slx`](https://github.com/feaksel/chb-inverter/blob/main/simulation/simulink/chb-5level-v2.slx) | Revised topology with the gate-drive sweep (IR2110 vs. TLP250) added. The IR2110 path is where the floating-reference failure showed up. |
| [`chb-5level-rl-nospike.slx`](https://github.com/feaksel/chb-inverter/blob/main/simulation/simulink/chb-5level-rl-nospike.slx) | LC-filtered variant with an RL load — used to characterize the wavy-current artefact and tune the snubber. |

<figure markdown="span">
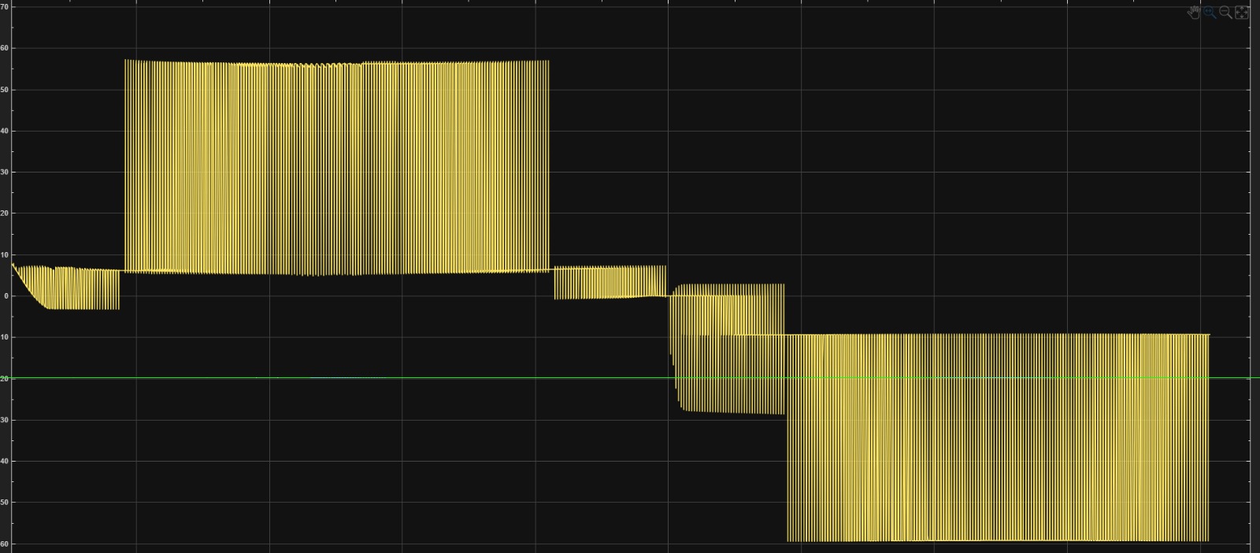
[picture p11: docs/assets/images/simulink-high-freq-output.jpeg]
Simulink — output at elevated switching frequency
  
  <figcaption>Simulink output at an elevated switching frequency — used during the parameter sweeps that informed the final 5 kHz choice. Higher f<sub>sw</sub> sharpens the output and pushes the ripple energy up where a smaller LC filter can attenuate it, at the cost of switching loss.</figcaption>
</figure>

## What the model does *not* capture

- **Parasitic inductance.** Gate-loop and DC-bus parasitics that cause real-world voltage spikes are not in the ideal-switch model. The snubber design (22 Ω 2 W + 2.2 nF / 630 V) was specified to bound these on the bench, not in simulation.
- **Dead time.** Simulink uses ideal complementary switches; the firmware enforces 3 µs dead time on the IRFB4110. Shoot-through margin is verified on the scope, not in the model.
- **Sensor noise + isolation.** The MCP3201 + 6N137 chain has SPI line inversion and rail-stuck detection in the firmware; none of that is reflected in the simulation's idealized sensor model.
- **Thermal coupling.** The model assumes both bridges at room temperature; the bench validation actually measured per-bridge MOSFET case temperatures.

The bench-validated numbers are what go into the [final report](../final-report/index.md). The simulation explains the *why* of the topology and gate-drive choices.

## See also

- [THD analysis](thd-analysis.md) — the FFT side-by-side and the per-harmonic content.
- [Model architecture](models.md) — block-by-block walk-through.
- [PSC vs. LSPWM design note](../design-notes/psc-vs-lspwm.md) — the cascade-balance argument that drove the switch from IPD to PSC after the simulation was complete.

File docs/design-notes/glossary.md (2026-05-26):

---
title: Glossary
---

# Glossary

Short definitions for terms used across this site. Not exhaustive — when in doubt, the [Build Guide v4.0](../hardware/build-guide-v4.md) is authoritative.

| Term | Meaning |
|---|---|
| **CHB** | Cascaded H-Bridge. A multilevel inverter topology where multiple H-bridges have their outputs summed. |
| **PSC-PWM** | Phase-Shifted Carrier Pulse-Width Modulation. Each bridge's carrier is shifted by 360°/N for N bridges, distributing switching events evenly across the cycle and giving better cascade balance than IPD. The as-built default. See [PSC vs. LSPWM](psc-vs-lspwm.md). |
| **IPD LS-PWM** | In-Phase Disposition Level-Shifted PWM. Earlier modulation strategy used in the project; superseded by PSC after the bridge-loss asymmetry showed up on the bench. |
| **STAIR / STAIR_ALT** | Two non-PWM modulators the firmware also ships — static-level selection rather than real PWM. STAIR is the known-good fallback; STAIR_ALT alternates which bridge carries the ±1 step. |
| **Dead time** | The deliberate gap between turning off one MOSFET of a half-bridge and turning on the other, preventing shoot-through. 3 µs on the as-built IRFB4110 stage; was 2 µs on the older IRFZ44N stage. |
| **Bootstrap** | The capacitor + diode arrangement that supplies the high-side gate driver's reference. Works for ground-referenced bridges; fundamentally cannot drive a floating CHB bridge. See [bootstrap fundamentals](bootstrap-fundamentals.md). |
| **TLP250** | Optically isolated gate driver (2.5 kV galvanic, LED → photodetector + MOSFET output stage) used on this project for every gate. Replaces the IR2110 bootstrap path that doesn't work in CHB. |
| **IR2110** | High-and-low-side bootstrap gate driver. Evaluated in Simulink for this project; the simulation collapsed on the upper bridge because bootstrap can't supply gate voltage referenced to a floating V<sub>S</sub>. Not used in the as-built. |
| **B0515S** | 1 W isolated 5 V → 15 V DC-DC converter; one per bridge, supplies the TLP250 rail without sharing ground with the controller. |
| **Isolated sensing** | ADC readings are taken on the floating bridge ground and crossed to the controller ground via opto-isolation (6N137 per signal). Keeps the controller from being damaged by bridge-side faults. |
| **SPIINV** | Runtime firmware command that sets a per-line inversion mask (bit 0 = SCK, bit 1 = CS, bit 2 = MISO) so the 6N137 inverters can be compensated without reflashing. `SPIINV 7` = all three lines inverted = standard one-6N137-per-line wiring. |
| **THD** | Total Harmonic Distortion — the fraction of the waveform's RMS that lies in harmonics other than the fundamental. Lower is better. Simulation predicted ~4.9% pre-filter at the headline operating point. |
| **MCP3201** | 12-bit successive-approximation ADC, DIP-8, SPI. Used for the isolated bridge-side voltage/current sensing, bit-banged at ≈ 140 kHz. |
| **ACS712** | Hall-effect-based current sensor, SOIC-8. One per bridge, on the bridge return. |
| **IRFB4110** | The N-channel power MOSFET used in the as-built single-bridge v4 modules. 100 V V<sub>DSS</sub>, 4.5 mΩ R<sub>DS(on)</sub>, 180 A. Replaces the IRFZ44N (55 V) from build-guide v3.1. |
| **IRFZ44N** | The build-guide-v3.1 MOSFET (55 V, 17.5 mΩ). Replaced by the IRFB4110 in iteration 4 for V<sub>DSS</sub> headroom and to resolve the TVS-clamp / V<sub>DSS</sub> mismatch. |
| **6N137** | High-speed (10 Mbit/s) digital optocoupler. One per SPI signal per island. Inverts (LED on → output low); the firmware compensates via SPIINV. |
| **VNOM** | Operator-set nominal per-bridge bus voltage (5–60 V). The firmware derives all DC-bus protection thresholds (UV, OV, IMBAL) as fractions of VNOM, so the inverter can be safely bench-tested below the 50 V design point. |
| **N-of-M debounce** | The firmware protection's noise-rejection scheme — a fault must be observed in 3 consecutive 1 kHz sensor scans (3 ms) before it trips. Single noisy samples don't trip. |
| **STM32 F303RE** | The MCU on the Nucleo-64 board used as the controller. Runs at 64 MHz from HSI/2 × PLL — no external crystal. |
| **Cereyan Hacıları** | Project team name. Literally "Current Pilgrims" in Turkish. |

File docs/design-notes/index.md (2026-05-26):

# Design notes

<figure markdown="span">
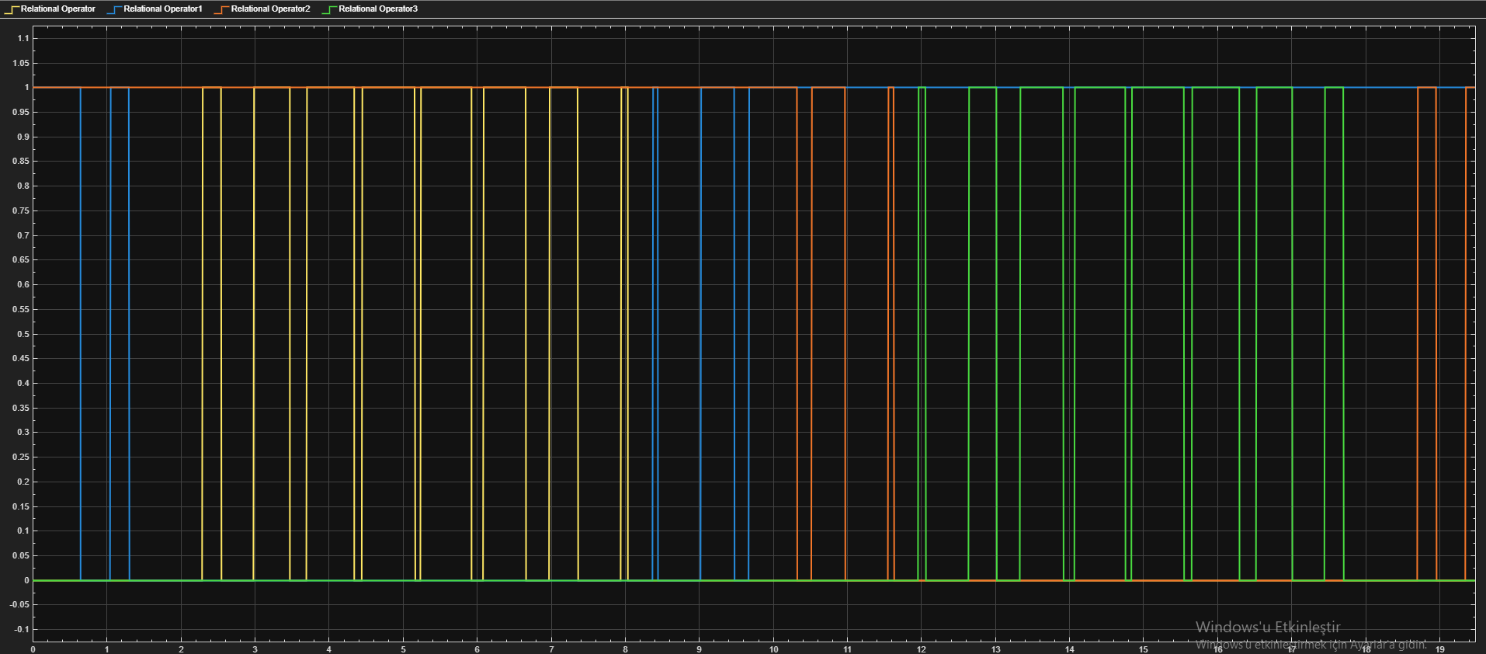
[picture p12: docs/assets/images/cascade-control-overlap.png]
Cascade-control overlap — modulation visual
  
  <figcaption>The two cells' carriers overlap to produce the cascade output. This visual ties together the modulation, isolation, and gate-drive arguments that each design note covers in detail.</figcaption>
</figure>

Standalone explanations of the engineering decisions that shaped the as-built design. Each note answers a single "why did we do it this way?" question. Drawn from the firmware CHANGELOG, the ELE 401 / 402 interim reports, the prior-chat design discussion, and the team's own bench experience.

| Note | Question it answers |
|---|---|
| [Bootstrap fundamentals](bootstrap-fundamentals.md) | How the high-side gate driver gets a reference, why bootstrap fails in CHB, and why the project uses isolated 15 V instead. |
| [CHB isolation](chb-isolation.md) | Why each bridge needs galvanic isolation from the controller, what specifically breaks without it, and how the as-built handles every isolation barrier. |
| [PSC vs. LSPWM](psc-vs-lspwm.md) | The cascade-balance argument that drove the switch from IPD level-shifted PWM to phase-shifted carriers. |
| [IGBT vs. MOSFET](igbt-vs-mosfet.md) | The quantitative loss analysis at 50 V / 5 kHz, why the IRFB4110 replaces the IRFZ44N from v3.1, and what changes in the firmware as a result. |
| [Grounding fix](grounding-fix.md) | The 5V_GND ↔ 50V_GND coupling issue that bit iteration 3 and how the 4-layer iteration-4 layout resolves it. |
| [Glossary](glossary.md) | Short definitions for terms used across this site. Read when an acronym or part number doesn't ring a bell. |

Each note is self-contained — read whichever the current decision touches. Cross-references point to the firmware source, the build guide, and the iteration history where relevant.

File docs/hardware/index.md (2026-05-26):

# Hardware

<figure markdown="span">
  Top-down KiCad render of the single-bridge v4 PCB
  <figcaption>Top-down KiCad render of the single-bridge v4 PCB. Two identical instances are cascaded to form the 5-level inverter.</figcaption>
</figure>

KiCad sources, gerbers, BOM, and photos for the **single-bridge v4** module — the board that was fabricated, populated, and demonstrated.

## Canonical reference

The authoritative engineering reference is **[Build Guide v4.0](build-guide-v4.md)** (May 2026). Everything in this section either summarizes the guide or links into it.

## Pages in this section

| Page | What it covers |
|---|---|
| [Architecture](architecture.md) | System block diagram, two-module cascade arithmetic, why each component was chosen. |
| [Build Guide v4.0](build-guide-v4.md) | As-built reference document — 15 sections covering hardware, firmware, bring-up, and known issues. |
| [BOM](bom.md) | Full bill of materials with Turkish supplier links — auto-rendered summary + link to `bom.csv`. |
| [Schematic](schematic.md) | KiCad hierarchical schematic — top + 7 subsheets (HS / LS / driver / 5V→15V / voltage-sense / current-sense). |
| [PCB layout](pcb-layout.md) | 4-layer stack-up details, 3D + top-down renders, gerber pack pointers. |
| [Populated photos](populated-photos.md) | Headline 100 V scope capture + demo-day photos + earlier bench-session gallery. |

## Conventions

- BOM has fixed columns: `Reference`, `Quantity`, `Value`, `Footprint`, `MPN`, `Supplier`, `Supplier Part Number`, `Supplier URL`, `Unit Cost TL`.
- Suppliers restricted to Turkish domestic vendors: Motorobit, Direnc.net, Robotistan, Komponentci.net.
- Passives default to through-hole (THT) for hand-assembly. Documented exceptions: ACS712 (SOIC-8), MCP3201 (DIP-8).
- Photos + KiCad PCB + gerbers + renders are tracked via Git LFS — see [`.gitattributes`](https://github.com/feaksel/chb-inverter/blob/main/.gitattributes). After `git clone`, run `git lfs install && git lfs pull`.

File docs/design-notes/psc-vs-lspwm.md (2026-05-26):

---
title: PSC vs. LSPWM
---

# PSC vs. LSPWM

<figure markdown="span">
  PSC cascade-output result on the scope
  <figcaption>PSC at the bench — five distinct cascade levels at 100 V output, no filter, both bridges thermally matched. The argument below explains why we got here from the earlier IPD path.</figcaption>
</figure>

> **Single-sentence summary.** The team simulated and partially implemented **IPD LS-PWM** (Level-Shifted Carrier PWM, In-Phase Disposition), then switched to **PSC-PWM** (Phase-Shifted Carriers) in the final firmware. The deciding factor was bridge-loss asymmetry — IPD makes Bridge 1 carry the inner-band switching forever; PSC distributes switching evenly across both bridges.

Both modulators produce the same 5 distinct cascade output levels (−2V<sub>DC</sub>, −V<sub>DC</sub>, 0, +V<sub>DC</sub>, +2V<sub>DC</sub>) for a 2-cell CHB. The difference is in **how each level is reached** — and that turns out to matter for thermal balance, switching loss, and bench-debug effort.

## How IPD LS-PWM produces 5 levels

Four triangular carriers are stacked vertically in the [0, 1] range and compared against one sinusoidal reference:

```text
  Reference: ─────── sin(ωt) ──────────
                                                 → level
  Carrier 1 (band [0.50, 1.00]):   <─~∨~─>      +2 if sin > C1
  Carrier 2 (band [0.00, 0.50]):   <─~∨~─>      +1 if sin > C2, else 0
  Carrier 3 (band [-0.50, 0.00]):  <─~∨~─>      -1 if sin > C3, else -2
  Carrier 4 (band [-1.00, -0.50]): <─~∨~─>      -2 if sin < C4
```

In this scheme, **Bridge 1** is mapped to the inner two carriers (bands ±0.5), and **Bridge 2** is mapped to the outer two (bands ±1.0). Bridge 1 switches every time the reference crosses C2 or C3 (every half-cycle, all the time). Bridge 2 only switches when the reference exceeds ±0.5 (near the sine peaks).

**Result:** Bridge 1 handles ≈ 70 % of the switching transitions; Bridge 2 handles ≈ 30 %. Under identical MOSFETs and identical gate drive, **Bridge 1's MOSFETs run hotter and its current sense reads higher than Bridge 2's.**

The team observed this asymmetry on the bench. One of Bridge 1's MOSFETs ran measurably warmer; current ratings on Bridge 1 ran ahead of Bridge 2. The original plan was to alternate which bridge takes the inner-band role every fundamental cycle (a "bridge swap" approach), but the implementation complexity was non-trivial and the result was still strictly worse than PSC.

## How PSC produces 5 levels

Two carriers, **phase-shifted by 360° / N = 180° / 2 = 90°** between bridges, each compared against the same sinusoidal reference using **unipolar** PWM:

```text
  Reference: ─────── sin(ωt) ──────────
                                                  → level
  Bridge 1 carrier (sawtooth, phase 0°):    each bridge produces -V, 0, or +V
  Bridge 2 carrier (sawtooth, phase 90°):   each bridge produces -V, 0, or +V

  Bridge 1 output:  3-level (±V_DC, 0)
  Bridge 2 output:  3-level (±V_DC, 0), shifted 90° in switching
  Cascade output:   5 levels — combinations of (B1 + B2) at any time
```

Both bridges switch the **same number of times per fundamental period**. Heat dissipation, current loading, and switching loss split symmetrically between them.

The 90° carrier shift gives **effective switching-frequency multiplication** — the cascade-output ripple appears at 2 × f<sub>sw</sub> = 10 kHz rather than the per-bridge 5 kHz. Better for any downstream LC filter.

## The PSC implementation gotcha

PSC needs the two cells' carriers to maintain exactly the right phase relationship. In firmware, this means **TIM1's counter and TIM8's counter must stay offset by exactly ARR/2** (where ARR is the period). If TIM8's counter drifts away from this offset, PSC degrades to **3-level output** — the cascade output stops producing the +V<sub>DC</sub> and -V<sub>DC</sub> intermediate levels, and the project deliverable spec ("5 levels visible on scope without a filter") fails.

The firmware hardens this with three things, from `firmware/stm32-f303re/Core/Src/pwm_modulator.c`:

1. **TIM8 CNT is written AFTER `CR1_CEN` is set**, so the post-`UG` (update generate) sequence cannot clobber it.
2. **The actual TIM8 − TIM1 offset is read back** after every `Pwm_SetConfig` call and exposed as `g_pwm_measured_cnt_offset` (ticks).
3. **A `lock` boolean** is published: `OK` if offset is within ±5 ticks of ARR/2, `BAD` otherwise. The `$C` config telemetry line reports both:
   `$C,...,cntoff=<N>,lock=OK|BAD`.

An operator who sees `lock=BAD` on the dashboard knows immediately that PSC won't produce 5-level output and can fall back to `STAIR_ALT` (a balanced staircase variant that's not real PWM but always gives the 5 distinct levels).

This was added specifically because the team did **not** want to discover the carrier-shift problem the hard way on the scope — having the lock-status diagnostic surfaced before any switching happens is the kind of defensive instrumentation that pays for itself the first time it catches a problem.

## Side-by-side

| | IPD LS-PWM | PSC |
|---|---|---|
| Distinct cascade levels | 5 (via stacked bands) | 5 (via phase-shifted modulation) |
| Bridge 1 switching events per cycle | ~70 % of total | ~50 % |
| Bridge 2 switching events per cycle | ~30 % of total | ~50 % |
| Thermal balance | **Asymmetric** (B1 hotter) | **Symmetric** |
| Cascade-output ripple frequency | f<sub>sw</sub> | 2 × f<sub>sw</sub> (90° phase shift) |
| Textbook THD (5 kHz, no filter) | ≈ 4.9 % | ≈ 4.4 % |
| Implementation complexity | Simpler — single timer config replicated | Requires precise TIM1 ↔ TIM8 phase offset |
| Debug-on-bench complexity | Easier — phase drift not a concern | Lock-status diagnostic mandatory |
| Project deliverable status | Bench-validated but bridge-imbalanced | **As-built default; symmetric and demoed** |

## Why PSC won

| Reason | Detail |
|---|---|
| **Symmetric thermal load** | Both bridges saw the same power dissipation under sustained 5 kHz operation — within ≈ 3 °C in the bench measurement. IPD would have required either much larger heatsinks on Bridge 1 or active bridge-swap firmware to even out the load. |
| **Lower textbook THD** | ≈ 0.5 % better than IPD. Not a huge gain, but free once the phase-shift implementation is solid. |
| **Better filter behavior** | The 2 × f<sub>sw</sub> effective output ripple makes any downstream LC filter half as big for the same attenuation. Relevant for the [LC filter roadmap item](../roadmap/lc-filter.md). |
| **The bench result** | The firmware's PSC implementation was validated at the demo: 5 distinct cascade levels on scope, lock=OK reported on telemetry, both bridges thermally matched. |

The trade was implementation complexity (the carrier-shift hardening) for a strictly better physical result.

Related: [Modulators reference](../firmware/modulators.md) (for the runtime command set), [Build Guide v4.0 §9](../hardware/build-guide-v4.md), and the firmware [CHANGELOG entry for `pwm-rewrite-configurable`](https://github.com/feaksel/chb-inverter/blob/main/firmware/stm32-f303re/CHANGELOG.md) for the design-decision narrative.

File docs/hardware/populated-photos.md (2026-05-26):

# Populated photos

Photos from the **bench bring-up** and **graduation demo day** for the as-built single-bridge v4 modules.

## Demo day — the hero shots

The team's demo of the running 5-level cascaded inverter.

<div class="grid" markdown>

Demo stand fully wired

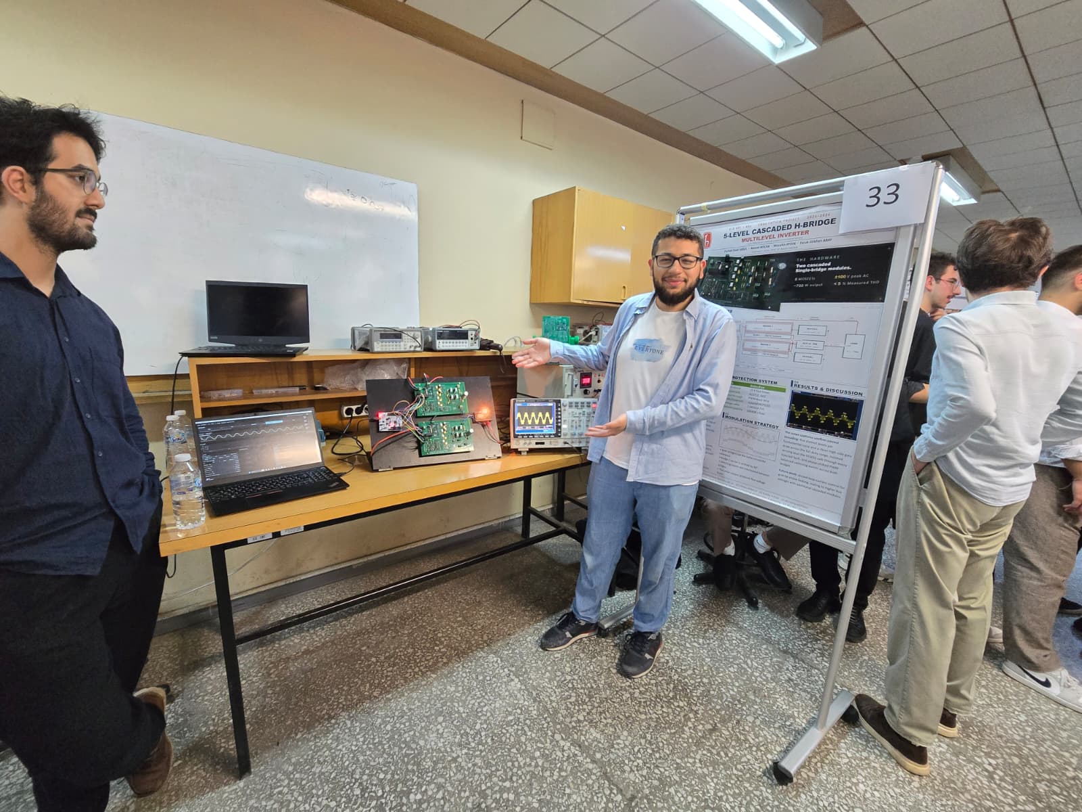
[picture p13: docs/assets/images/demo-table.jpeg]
Demo table


Lab testing setup

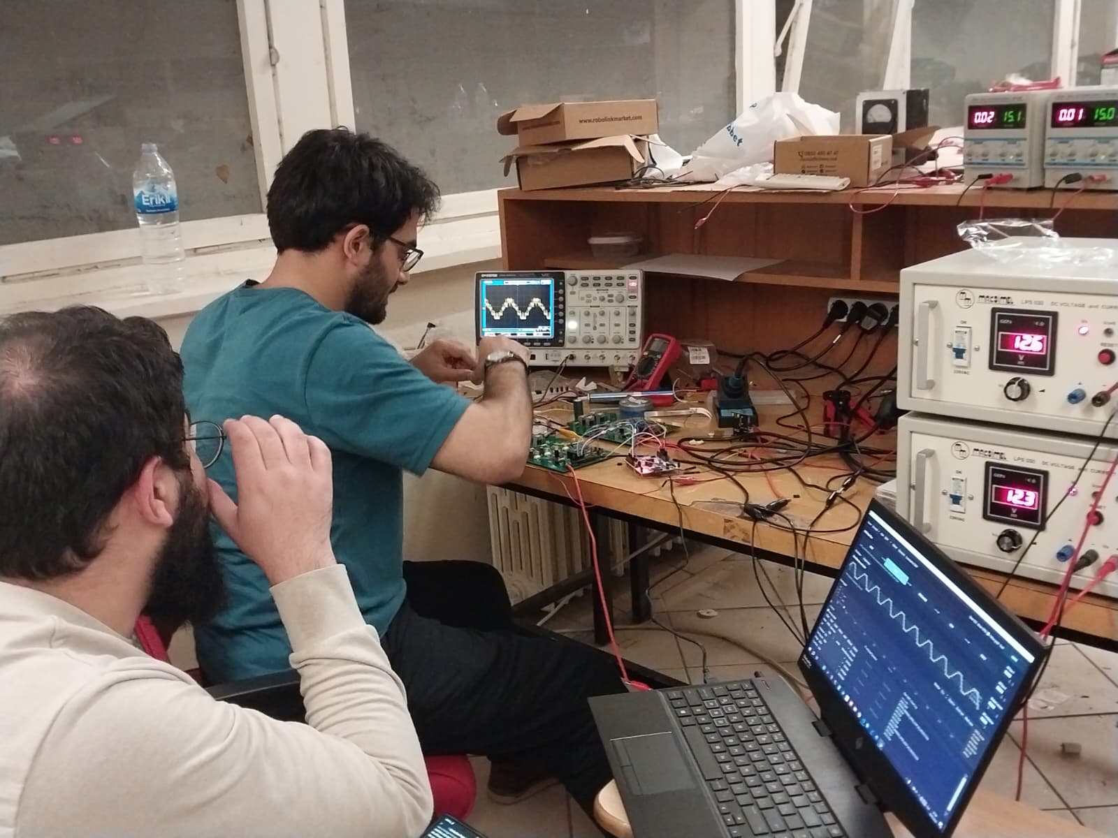
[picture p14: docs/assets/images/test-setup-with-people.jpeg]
Test setup with team


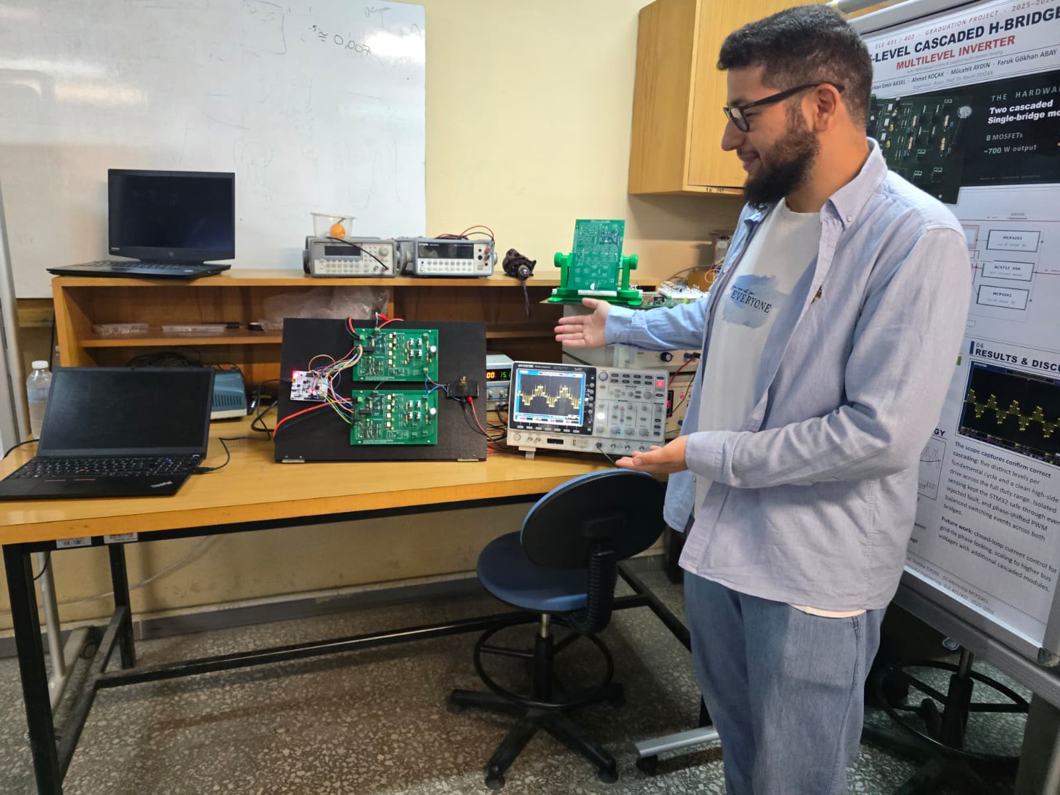
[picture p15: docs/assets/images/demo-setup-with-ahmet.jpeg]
Demo setup — Ahmet at the bench


Cereyan Hacıları on the demo stand

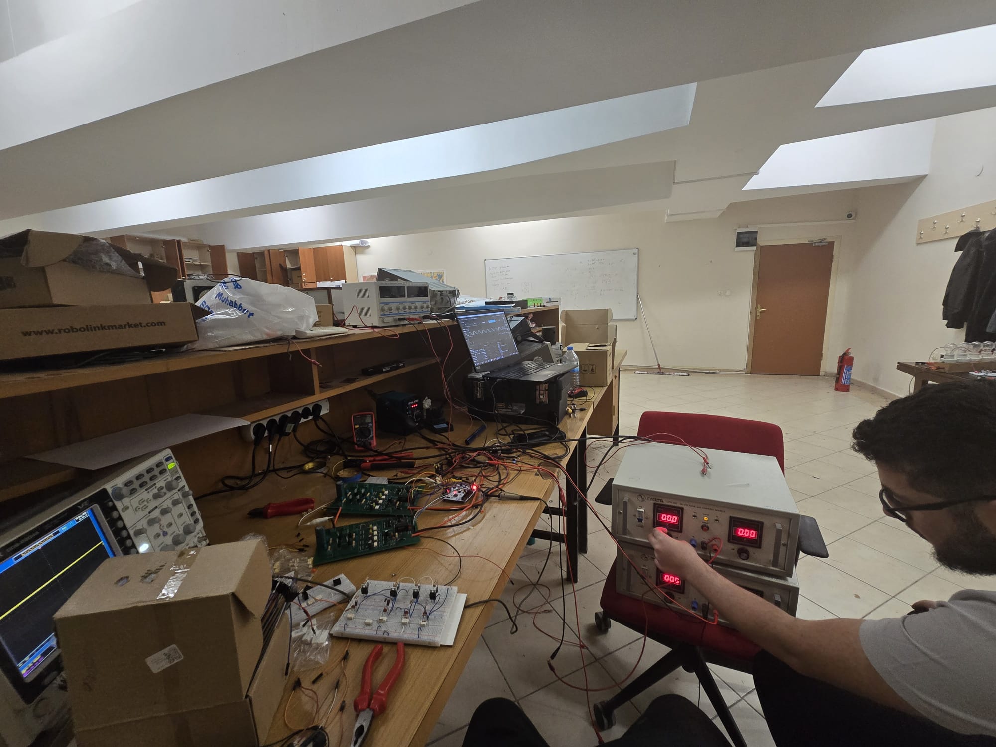
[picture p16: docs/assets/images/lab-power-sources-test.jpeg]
Lab power sources test


</div>

## Oscilloscope captures

### Headline — 100 V output, 5 distinct cascade levels

The project deliverable, captured on the scope at the demo:

100 V output, 5 distinct cascade levels under sustained PSC-PWM at 5 kHz, no filter

This is the result that satisfies the graduation spec: **5 distinct cascade output levels visible without an output filter**, at 100 V cascade output, under sustained operation. Both bridges thermally balanced; no protection trips during the run.

### Other scope traces

Other captures from the PSC bench run — earlier sweeps that show the path to the headline above:

<div class="grid" markdown>

PSC cascade output on scope

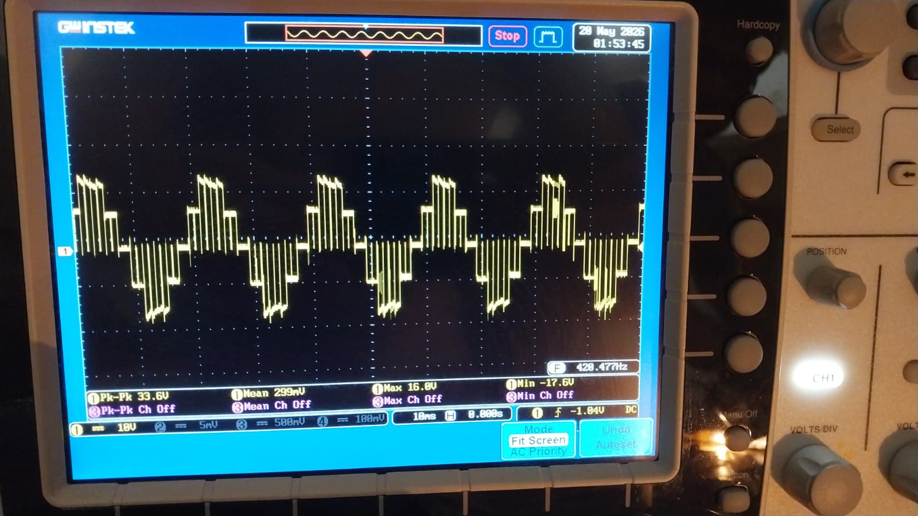
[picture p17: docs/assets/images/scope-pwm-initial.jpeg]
PWM at the scope — initial capture


PWM working — early scope capture

PWM at the correct frequency

Full correct PWM output

</div>

## Earlier bench session (2026-03-05)

Photos from a mid-development bench day, before the final cleanup. Useful for context — they show the boards in their bring-up configuration.

<div class="grid" markdown>

Bench at 12:06

Bench at 13:09 — first capture

Bench at 13:09 — second capture

Bench at 14:19

Bench at 16:26 — first capture

Bench at 16:26 — second capture

</div>

## Earlier breadboard prototype

For continuity, the earlier breadboard half-bridge with the gate-drive LED visibly switching during bring-up of the gate drive itself:

Breadboard half-bridge with LED lit

This is **not** the as-built PCB — it is the team's debug rig used while characterizing the gate drive before committing to the PCB layout.

## What's still pending

- More dead-time scope captures (rising / falling edge zoom).
- Thermal scan of the bridges under sustained PSC load.
- Individual close-up shots of each populated PCB module (top + bottom).

(Tracked at [`_AGENT_TRACKER.md`](https://github.com/feaksel/chb-inverter/blob/main/_AGENT_TRACKER.md) — artifact #8.)

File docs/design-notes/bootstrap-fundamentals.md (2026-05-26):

---
title: Bootstrap fundamentals
---

# Bootstrap fundamentals

> **Single-sentence summary.** Bootstrap gate drive — the standard cheap way to drive a high-side N-channel MOSFET — works flawlessly in ground-referenced bridges and fails fundamentally in cascaded floating bridges. This project does **not** use bootstrap for the high-side gate; it uses optical isolation (TLP250) with an isolated 15 V rail per bridge (B0515S).

## The classical bootstrap arrangement

A half-bridge with both MOSFETs being N-channel needs the high-side gate driven 10–15 V **above** the high-side source (V<sub>S</sub>) — not above ground. The bootstrap arrangement provides that voltage without an isolated supply:

```mermaid
flowchart LR
    Vcc[V_CC = 15 V] --> BD[Boot diode]
    BD --> BC((Boot cap))
    BC --> VB[V_B<br/>high-side<br/>driver supply]
    VB --> HSDrv[High-side<br/>gate driver]
    HSDrv --> HSGate[HS MOSFET<br/>gate]
    HSDrv --> Vs[V_S<br/>connects to<br/>HS source]
    BC --> Vs
    Vs -.->|when LS is ON| GND[(GND)]
```

When the **low-side MOSFET is conducting**:
- V<sub>S</sub> is pulled to ≈ GND through the LS MOSFET.
- The bootstrap diode is forward-biased and the bootstrap cap charges from V<sub>CC</sub> to ≈ V<sub>CC</sub> − V<sub>diode</sub>.

When the **high-side MOSFET is turned on**:
- V<sub>S</sub> rises toward V<sub>DC</sub> (the bridge bus).
- The bootstrap cap rides up with V<sub>S</sub> — the cap maintains V<sub>B</sub> ≈ V<sub>S</sub> + (V<sub>CC</sub> − V<sub>diode</sub>).
- The high-side driver now has its 10–15 V supply referenced to the (now-floating) V<sub>S</sub>.

The bootstrap diode prevents the cap from discharging back into V<sub>CC</sub> when V<sub>S</sub> rises. Total parts count: one diode, one cap. Cheap, well-understood, and the reason the IR2110 has been the workhorse gate driver for ground-referenced bridges for 30+ years.
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

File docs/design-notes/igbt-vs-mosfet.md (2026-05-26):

---
title: IGBT vs. MOSFET
---

# IGBT vs. MOSFET

> **Single-sentence summary.** At the project's operating point (50 V per bridge, 5 kHz switching, ≈ 400 W total), every loss term favors MOSFETs. The choice was unambiguous and quantitative — not a preference call.

## The classical crossover

For a power switch in an inverter, the relevant figures of merit are **conduction loss** (the loss while the switch is fully on, carrying current) and **switching loss** (the loss during the transition between on and off, each PWM period). The two technologies make opposite trade-offs:
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

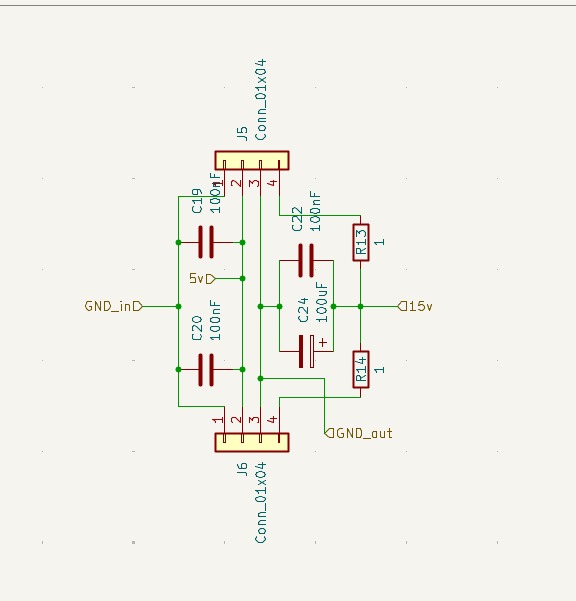
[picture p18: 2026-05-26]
docs/assets/images/schematic-5v-15v.jpg

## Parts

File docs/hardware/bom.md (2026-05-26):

---
title: Bill of materials
---

# Bill of materials

<figure markdown="span">
  Top-down KiCad render — the board this BOM populates
  <figcaption>The single-bridge v4 PCB. Two identical instances of this board are populated from the BOM below; the project total is two modules + spares.</figcaption>
</figure>

The full BOM is at [`hardware/single-bridge-v4/bom.csv`](https://github.com/feaksel/chb-inverter/blob/main/hardware/single-bridge-v4/bom.csv) in the repository (GitHub renders CSV as a sortable table). The original BOM spreadsheet sources are also kept alongside for traceability:

| Source | Purpose |
|---|---|
| [`bom-source-v3_2.xlsx`](https://github.com/feaksel/chb-inverter/blob/main/hardware/single-bridge-v4/bom-source-v3_2.xlsx) | Original BOM authored against build guide v3.2. Lives next to the canonical CSV. |
| [`kicad-footprints.xlsx`](https://github.com/feaksel/chb-inverter/blob/main/hardware/single-bridge-v4/kicad-footprints.xlsx) | Footprint catalogue used during the KiCad netlist export. |
| [`hardware/legacy/iteration-3/CHB_BOM_v3_1.xlsx`](https://github.com/feaksel/chb-inverter/blob/main/hardware/legacy/iteration-3/CHB_BOM_v3_1.xlsx) | The older v3.1 BOM (IRFZ44N + IPD LS-PWM era). Preserved for iteration-history reference. |

## Headline totals (v3.2, project as a whole)

| Section | Items | Need qty | Subtotal (TL) |
|---|---:|---:|---:|
| A. Power semiconductors | 6 | 28 | 1 151.6 |
| B. Sensing ICs | 4 | 12 | 539.0 |
| C. DC-bus bulk + protection | 3 | 5 | 86.0 |
| D. Gate-drive passives | 4 | 60 | 24.0 |
| E. Bootstrap | 1 | 4 | 6.0 |
| F. Snubber | 2 | 16 | 36.0 |
| G. Isolated supply passives | 2 | 6 | 3.2 |
| H. DC-bus sensing passives | 5 | 13 | 5.8 |
| I. Current-sense passives | 2 | 2 | 0.6 |
| J. Connectors + mechanical | 5 | 35 | 132.5 |
| **Project total** | **34 lines** | **181 parts** | **≈ 1 985 TL** |

(All figures from `bom-source-v3_2.xlsx` "Complete BOM" sheet, recomputed for the as-built two-module project.)

## Notable substitutions and gaps

!!! warning "MOSFET — IRFB4110 substituted for IRFZ44N at order time"
    The v3.2 source spreadsheet lists **IRFZ44N** (55 V, 49 A, 17.5 mΩ) at line A.1, but the as-built hardware uses **IRFB4110** (100 V, 180 A, 4.5 mΩ). The substitution is documented in the firmware CHANGELOG ([dead-time raised to 3 µs for the IRFB4110 power stage](https://github.com/feaksel/chb-inverter/blob/main/firmware/stm32-f303re/CHANGELOG.md)) and in [Build Guide v4.0 §4 Power stage](build-guide-v4.md). The canonical `bom.csv` lists IRFB4110 with a `TBD` Motorobit URL pending confirmation.

!!! info "Reference designators are placeholders"
    The `Reference` column in `bom.csv` uses ranges (Q1-Q4, R1, etc.) derived from the schematic structure. These are placeholders — the authoritative reference designators come from the KiCad annotation. They will be replaced after a `tools/bom-validator.py` cross-check against the KiCad netlist (planned).

!!! info "Per-module vs. per-project quantities"
    The v3.2 source BOM lists **project totals** (two modules + spares). The canonical `bom.csv` follows the same convention. Per-module quantities are roughly half the `Need` column for most line items; sensing ICs split asymmetrically between the lower-bridge island (1× MCP3201) and the upper-bridge island (2× MCP3201).

## Suppliers (Turkish domestic, by line frequency)

| Supplier | Lines | Typical contents |
|---|---:|---|
| Direnc.net | 20 | Passives, MCP3201, fast diodes, connectors |
| Motorobit | 11 | MOSFETs, TLP250, B0515S DC-DC, ACS712, 6N137, 78L05, TVS |
| Robotistan | 3 | Fuse holders, heatsinks, wire |

International suppliers (Mouser / Digi-Key / LCSC) are **not used** by project preference — all parts come from the four approved Turkish vendors. See [project conventions](../hardware/index.md#conventions).

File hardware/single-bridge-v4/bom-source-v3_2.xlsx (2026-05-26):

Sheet: Complete BOM
5-LEVEL CHB INVERTER — COMPLETE BOM v3.2 (Motorobit Optimized, No Mouser)
# | Component | Value / Spec | Pkg | Need | Spare | Total | Role / Circuit Location | Best Source | Stock Status | Unit (TL) | Subtotal (TL) | Link
A. POWER SEMICONDUCTORS
1 | IRFZ44N MOSFET | 55V 49A 17.5mΩ | TO-220 | 8 | 4 | 12 | H-bridge switches (Q1-Q4 ×2) | Motorobit | STOKTA | 18.00 | 216.00 | Motorobit (https://www.motorobit.com/irfz44n-55v-49a-mosfet-to220)
2 | TLP250 Gate Driver DIP | 2500Vrms isol. | DIP-8 | 8 | 2 | 10 | Isolated gate driver (1/MOSFET) | Motorobit | STOKTA | 40.00 | 400.00 | Motorobit (https://www.motorobit.com/tlp250-dip-8-optocoupler-ic-with-mosfet-driver-output)
3 | B0515S-1WR3 DC-DC | 5V→15V 1W isolated | SIP-4 | 4 | 2 | 6 | Isolated 15V supply (2 paralel/bridge) | Motorobit | STOKTA | 78.00 | 468.00 | Motorobit (https://www.motorobit.com/b0515s-1wr3-dc-dc-1w-45-55v-input-15v-output-voltage-converter)
4 | 1N5408 Diode | 3A 1000V rectifier | DO-201 | 2 | 2 | 4 | Reverse polarity koruma | Direnc.net | STOKTA (28707) | 2.50 | 10.00 | Direnc.net (https://www.direnc.net/1n5408-do201-3a-1000v-diyot)
5 | UF4007 Fast Diode | 1A 1000V 75ns | DO-41 | 4 | 4 | 8 | Bootstrap diyot (4 HS kanal) | Direnc.net | STOKTA (99999) | 2.20 | 17.60 | Direnc.net (https://www.direnc.net/uf4007-1a-1000v-tht-hizli-diyot-do41)
6 | 1.5KE62A TVS Diode | 53V standoff 84.5V clamp | DO-201 | 2 | 2 | 4 | Transient voltage clamp (1/bridge) | Motorobit | STOKTA | 10.00 | 40.00 | Motorobit (https://www.motorobit.com/transil-diyot)
B. SENSING ICs
7 | ACS712-20A Module | Hall-effect 100mV/A | Module | 1 | 1 | 2 | AC çıkış akım sensörü | Motorobit | STOKTA (20A!) | 55.00 | 110.00 | Motorobit (https://www.motorobit.com/20-to-20a-acs712-current-sensor)
8 | MCP3201 ADC | 12-bit SPI single ch | DIP-8 | 3 | 1 | 4 | İzoleli DC bus ADC ×2 + akım ADC ×1 | Direnc.net | STOKTA (27) | 81.00 | 324.00 | Direnc.net (https://www.direnc.net/mcp3201-dip8-analog-dijital-cevirici-entegre)
9 | 6N137 Optocoupler DIP | 10Mbit/s high-speed | DIP-8 | 6 | 2 | 8 | SPI izolasyon: 3/bridge (SCK,CS,MISO) | Motorobit | STOKTA | 12.00 | 96.00 | Motorobit (https://www.motorobit.com/6n137-dip-8-digital-output-optocoupler-ic)
10 | 78L05 Regulator | 5V 100mA linear | TO-92 | 2 | 1 | 3 | Island lojik beslemesi (15V→5V) | Motorobit | STOKTA | 3.00 | 9.00 | Motorobit (https://www.motorobit.com/78l05-voltaj-regulatoru-to92)
C. DC BUS KAPASITÖRLER & KORUMA
11 | Electrolytic Cap | 1000µF / 100V | Radial | 2 | 0 | 2 | DC link bulk depolama | Direnc.net | STOKTA | 25.00 | 50.00 | Direnc.net (https://www.direnc.net/kondansatorler)
12 | Bleeder Resistor | 100kΩ / 2W | Axial | 2 | 0 | 2 | Güvenlik deşarj | Direnc.net | STOKTA | 2.00 | 4.00 | Direnc.net (https://www.direnc.net/direncler)
13 | Blade Fuse+Holder | 15A | Standard | 2 | 2 | 4 | Kısa devre koruma | Robotistan | STOKTA | 8.00 | 32.00 | Robotistan (https://www.robotistan.com/)
D. GATE DRIVE PASİFLER (×8 kanal)
14 | Resistor 220Ω | 1/4W 5% | Axial | 14 | 0 | 14 | TLP250 LED limit (8) + 6N137 LED (6) | Direnc.net | STOKTA (99999) | 0.30 | 4.20 | Direnc.net (https://www.direnc.net/direncler)
15 | Resistor 22Ω 1/4W | 1/4W 5% | Axial | 8 | 0 | 8 | Gate seri direnç | Direnc.net | STOKTA (99999) | 0.30 | 2.40 | Direnc.net (https://www.direnc.net/direncler)
16 | Resistor 10kΩ | 1/4W 5% | Axial | 8 | 0 | 8 | Gate-source pull-down | Direnc.net | STOKTA (99999) | 0.30 | 2.40 | Direnc.net (https://www.direnc.net/direncler)
17 | Ceramic Cap 100nF | 100nF / 25V | THT | 30 | 0 | 30 | TLP250+6N137+MCP3201+B0515+div+bypass | Direnc.net | STOKTA (99999) | 0.50 | 15.00 | Direnc.net (https://www.direnc.net/kondansatorler)
E. BOOTSTRAP (×4 HS kanal)
18 | Cap 10µF | 10µF / 25V | THT | 4 | 0 | 4 | Bootstrap enerji depolama | Direnc.net | STOKTA | 1.50 | 6.00 | Direnc.net (https://www.direnc.net/kondansatorler)
F. SNUBBER (×8 MOSFET)
19 | Resistor 22Ω 2W | 2W wire-wound | Axial | 8 | 0 | 8 | Snubber sönümleme (D-S arası) | Direnc.net | STOKTA | 1.50 | 12.00 | Direnc.net (https://www.direnc.net/direncler)
20 | Film Cap 2.2nF | 2.2nF / 630V | Box | 8 | 0 | 8 | Snubber cap (22Ω ile seri) | Direnc.net | STOKTA | 3.00 | 24.00 | Direnc.net (https://www.direnc.net/kondansatorler)
G. İZOLE BESLEME PASİFLER (×2 bridge)
21 | Resistor 1Ω | 1/4W | Axial | 4 | 0 | 4 | B0515S akım dengeleme | Direnc.net | STOKTA | 0.30 | 1.20 | Direnc.net (https://www.direnc.net/direncler)
22 | Electrolytic 100µF | 100µF / 25V | Radial | 2 | 0 | 2 | B0515S çıkış filtre | Direnc.net | STOKTA | 1.00 | 2.00 | Direnc.net (https://www.direnc.net/kondansatorler)
H. DC BUS SENSING PASİFLER (×2 island)
23 | Resistor 100kΩ 1% | 1/4W metal film | Axial | 2 | 0 | 2 | Voltaj bölücü üst | Direnc.net | STOKTA | 0.50 | 1.00 | Direnc.net (https://www.direnc.net/direncler)
24 | Resistor 5.1kΩ 1% | 1/4W metal film | Axial | 2 | 0 | 2 | Voltaj bölücü alt | Direnc.net | STOKTA | 0.50 | 1.00 | Direnc.net (https://www.direnc.net/direncler)
25 | Resistor 4.7kΩ | 1/4W | Axial | 6 | 0 | 6 | 6N137 çıkış pull-up | Direnc.net | STOKTA | 0.30 | 1.80 | Direnc.net (https://www.direnc.net/direncler)
26 | Cap 1µF ceramic | 1µF / 25V | THT | 2 | 0 | 2 | 78L05 giriş filtre | Direnc.net | STOKTA | 1.00 | 2.00 | Direnc.net (https://www.direnc.net/kondansatorler)
27 | Electrolytic 10µF | 10µF / 16V | Radial | 2 | 0 | 2 | 78L05 çıkış filtre | Direnc.net | STOKTA | 0.50 | 1.00 | Direnc.net (https://www.direnc.net/kondansatorler)
I. AKIM SENSOR PASİFLER (safe side)
28 | Resistor 1kΩ | 1/4W | Axial | 1 | 0 | 1 | ACS712 bölücü üst | Direnc.net | STOKTA | 0.30 | 0.30 | Direnc.net (https://www.direnc.net/direncler)
29 | Resistor 1.5kΩ | 1/4W | Axial | 1 | 0 | 1 | ACS712 bölücü alt | Direnc.net | STOKTA | 0.30 | 0.30 | Direnc.net (https://www.direnc.net/direncler)
J. KONNEKTÖR & MEKANİK
30 | Screw Terminal 2-pos | 15A+ 5.08mm | PCB | 6 | 0 | 6 | 4×DC giriş + 2×AC çıkış | Direnc.net | STOKTA | 5.00 | 30.00 | Direnc.net (https://www.direnc.net/konnektorler)
31 | Pin Header 2×10 | 2.54mm male | THT | 1 | 1 | 2 | Controller interface | Direnc.net | STOKTA | 3.00 | 6.00 | Direnc.net (https://www.direnc.net/konnektorler)
32 | Heatsink TO-220 | Clip-on | TO-220 | 8 | 0 | 8 | MOSFET soğutucu | Robotistan | STOKTA | 5.00 | 40.00 | Robotistan (https://www.robotistan.com/)
33 | 18 AWG Wire | Silikon kırmızı+siyah | 2m ea. | 1 | 0 | 1 | Güç kablolama | Robotistan | STOKTA | 30.00 | 30.00 | Robotistan (https://www.robotistan.com/)
34 | DIP-8 IC Socket | 8-pin turned pin | DIP-8 | 17 | 0 | 17 | TLP250(8)+6N137(6)+MCP3201(3) soketi | Direnc.net | STOKTA | 1.50 | 25.50 | Direnc.net (https://www.direnc.net/entegre-soketleri)
TOPLAM / GRAND TOTAL |  |  |  |  |  | 205 |  |  |  |  | 1984.70 TL

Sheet: Alışveriş Listesi (Site)
SİPARİŞ LİSTESİ — SİTEYE GÖRE GRUPLANMIŞ (3 site, Mouser yok!)
Site | Komponent | Adet | Birim (TL) | Ara Toplam (TL) | Link | Not / Stok
📦 MOTOROBİT — motorobit.com
 | IRFB4110 - 100V 180A Mosfet - TO220 | 12 | 80.00 | 960.00 | IRFB4110N (https://www.motorobit.com/irfb4110-100v-180a-mosfet-to220-en?utm_source=chatgpt.com) | Stokta. 8+4 yedek
 | TLP250 DIP-8 Gate Driver | 10 | 53.00 | 530.00 | TLP250 DIP (https://www.motorobit.com/tlp250-dip-8-optocoupler-ic-with-mosfet-driver-output) | Stokta. DIP-8 versiyonu mevcut!
 | B0515S-1WR3 DC-DC 5V→15V | 6 | 133.00 | 798.00 | B0515S-1WR3 (https://www.motorobit.com/b0515s-1wr3-dc-dc-1w-45-55v-input-15v-output-voltage-converter) | Stokta! 93.24 TL KDV dahil. MOUSER GEREKMİYOR
 | 1.5KE62A TVS Diode | 4 | 10.00 | 40.00 | 1.5KE62A (https://www.motorobit.com/transil-diyot) | Stokta! 9.72 TL KDV dahil. MOUSER GEREKMİYOR
 | ACS712-20A Current Sensor | 2 | 55.00 | 110.00 | ACS712 20A (https://www.motorobit.com/20-to-20a-acs712-current-sensor) | Stokta — 20A modül mevcut (100mV/A)
 | 6N137 DIP-8 Optocoupler | 8 | 12.00 | 96.00 | 6N137 DIP (https://www.motorobit.com/6n137-dip-8-digital-output-optocoupler-ic) | Stokta. DIP-8 versiyonu mevcut!
 | UF4007 1A 1000V Fast Diode | 8 | 2.20 | 17.60 | UF4007 (https://www.motorobit.com/uf4007-1000v-1a-fast-diode) | 99999 stokta
 | 15A Blade Fuse + Holder | 4 | 8.00 | 32.00 | Sigorta (https://www.motorobit.com/15-amper-oto-sigorta-bicak-sigorta) | Otomotiv tipi
 | Heatsink TO-220 Clip-on | 8 | 5.00 | 40.00 | Soğutucu (https://www.motorobit.com/to220-aluminyum-sogutucu-heatsink-15x10x20mm) | MOSFET termal yönetim
 | 78L05 TO-92 Regulator | 3 | 3.00 | 9.00 | 78L05 TO-92 (https://www.motorobit.com/78l05-voltaj-regulatoru-to92) | Stokta
 | 18AWG Silikon Kablo (R+B) | 1 | 30.00 | 30.00 | Kablo (https://www.motorobit.com/18-awg-silikon-kablo-kirmizi-1-metre) | 2m kırmızı + 2m siyah
MOTOROBİT ARA TOPLAM: |  |  |  | 2662.60 TL
📦 DİRENÇ.NET — direnc.net
 | MCP3201 DIP-8 ADC | 4 | 81.00 | 324.00 | MCP3201 DIP (https://www.direnc.net/mcp3201-dip8-analog-dijital-cevirici-entegre) | 27 stokta. 3+1 yedek. Erken sipariş ver!
 | 1N5408 3A 1000V Diode | 4 | 2.50 | 10.00 | 1N5408 (https://www.direnc.net/1n5408-do201-3a-1000v-diyot) | 28707 stokta
 | 1000µF 100V Electrolytic | 2 | 25.00 | 50.00 | 1000µF (https://www.direnc.net/kondansatorler) | DC link bulk
 | 100µF 25V Electrolytic | 2 | 1.00 | 2.00 | 100µF (https://www.direnc.net/kondansatorler) | B0515S filtre
 | 10µF 25V (bootstrap) | 4 | 1.50 | 6.00 | 10µF 25V (https://www.direnc.net/kondansatorler) | Bootstrap caps
 | 10µF 16V Electrolytic | 2 | 0.50 | 1.00 | 10µF 16V (https://www.direnc.net/kondansatorler) | 78L05 çıkış
 | 1µF 25V Ceramic | 2 | 1.00 | 2.00 | 1µF (https://www.direnc.net/kondansatorler) | 78L05 giriş
 | 100nF Ceramic TOPLU | 30 | 0.50 | 15.00 | 100nF bulk (https://www.direnc.net/kondansatorler) | Tüm bypass: TLP250+6N137+MCP3201+B0515+div
 | 2.2nF 630V Film Cap | 8 | 3.00 | 24.00 | 2.2nF 630V (https://www.direnc.net/kondansatorler) | Snubber cap — yüksek voltaj film
 | Dirençler karışık (220Ω×14, 22Ω×8, 10kΩ×8, 4.7kΩ×6, 1Ω×4, 100kΩ 1%×2, 5.1kΩ 1%×2, 1kΩ×1, 1.5kΩ×1) | 46 | 0.35 | 16.10 | Dirençler (https://www.direnc.net/direncler) | Tümü 1/4W, metal film 1% olanlar ayrı al
 | Resistor 22Ω 2W | 8 | 1.50 | 12.00 | 22Ω 2W (https://www.direnc.net/direncler) | Snubber — 2W dikkat!
 | Resistor 100kΩ 2W | 2 | 2.00 | 4.00 | 100kΩ 2W (https://www.direnc.net/direncler) | Bleeder — 2W
 | Screw Terminal 2-pos 15A+ | 6 | 5.00 | 30.00 | Klemens (https://www.direnc.net/konnektorler) | 5.08mm PCB mount
 | Pin Header 2×10 | 2 | 3.00 | 6.00 | Header (https://www.direnc.net/konnektorler) | Controller arayüz
 | DIP-8 IC Socket | 17 | 1.50 | 25.50 | DIP-8 Soket (https://www.direnc.net/entegre-soketleri) | TLP250(8)+6N137(6)+MCP3201(3)
DİRENÇ.NET ARA TOPLAM: |  |  |  | 527.60 TL
 |  |  | Real toplam | 691
TAHMİNİ GENEL TOPLAM: |  |  |  | ≈1300-1500 TL
✅ MOUSER GEREKMİYOR! B0515S-1WR3 ve 1.5KE62A artık Motorobit'ten alınıyor.
✅ ACS712-20A modül Motorobit'te stokta! (Direnc.net ve Robotistan'da 20A yok)
✅ TLP250 DIP-8 ve 6N137 DIP-8 Motorobit'te stokta! (Direnc.net'te sadece SMD var)
📦 Motorobit: 1500 TL üzeri kargo bedava, 15:00'a kadar sipariş aynı gün kargoda
📦 Direnc.net: 1500 TL üzeri kargo bedava. Pasifler için ana kaynak.
📦 Robotistan: Sadece mekanik bileşenler (soğutucu, sigorta, kablo). Kargo ~30-40 TL.
⚠️ MCP3201: Direnc.net'te sadece 27 adet stokta. 4 adet lazım — erken sipariş önerilir.
💡 Sipariş stratejisi: Önce Motorobit (IC'ler), sonra Direnc.net (pasifler), son Robotistan.
💰 Fiyatlar KDV dahil tahminidir (Şubat 2026). Stok durumları anlık değişebilir.

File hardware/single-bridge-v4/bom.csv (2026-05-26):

Reference | Quantity | Value | Footprint | MPN | Supplier | Supplier Part Number | Supplier URL | Unit Cost TL | Subtotal TL | Role
Q1-Q4 | 4 | IRFB4110 (per module — replaces IRFZ44N from v3.2 BOM) | TO-220 | IRFB4110 | Motorobit | TBD | https://www.motorobit.com/ | TBD | TBD | H-bridge power switch. Substituted for IRFZ44N at order time — see CHANGELOG/build-guide §4.
U1-U4 | 4 | TLP250 isolated gate driver | DIP-8 | TLP250 | Motorobit | TLP250 | https://www.motorobit.com/tlp250-dip-8-optocoupler-ic-with-mosfet-driver-output | 40.0 | 160.0 | One per MOSFET — true galvanic isolation (2.5 kV); mandatory for CHB floating bridge.
U5-U6 | 2 | B0515S-1WR3 5V→15V isolated DC-DC | SIP-4 | B0515S-1WR3 | Motorobit | B0515S-1WR3 | https://www.motorobit.com/b0515s-1wr3-dc-dc-1w-45-55v-input-15v-output-voltage-converter | 78.0 | 156.0 | Isolated 15 V rail for the TLP250s (two in parallel per bridge).
D1 | 1 | 1N5408 3A 1000V rectifier | DO-201 | 1N5408 | Direnc.net | 1N5408 | https://www.direnc.net/1n5408-do201-3a-1000v-diyot | 2.5 | 2.5 | Reverse-polarity protection at the DC input.
D2-D5 | 4 | UF4007 1A 1000V 75ns fast diode | DO-41 | UF4007 | Direnc.net | UF4007 | https://www.direnc.net/uf4007-1a-1000v-tht-hizli-diyot-do41 | 2.2 | 8.8 | Bootstrap diode (one per high-side channel).
D6 | 1 | 1.5KE62A TVS diode (84.5 V clamp) | DO-201 | 1.5KE62A | Motorobit | 1.5KE62A | https://www.motorobit.com/transil-diyot | 10.0 | 10.0 | Transient-voltage clamp on the DC bus.
U7 | 1 | ACS712-20A current sensor module | Module | ACS712-20A | Motorobit | ACS712-20A | https://www.motorobit.com/20-to-20a-acs712-current-sensor | 55.0 | 55.0 | Hall-effect current sensor (100 mV/A) on the AC output.
U8-U9 | 2 | MCP3201 12-bit SPI ADC | DIP-8 | MCP3201 | Direnc.net | MCP3201 | https://www.direnc.net/mcp3201-dip8-analog-dijital-cevirici-entegre | 81.0 | 162.0 | Isolated bus ADC + current ADC. Two per module (DC bus + bridge current share an isolated MISO on PC3).
U10-U12 | 3 | 6N137 high-speed optocoupler | DIP-8 | 6N137 | Motorobit | 6N137 | https://www.motorobit.com/6n137-dip-8-digital-output-optocoupler-ic | 12.0 | 36.0 | SPI isolation: SCK + CS + MISO per island. The 6N137 inverts — firmware compensates via SPIINV.
U13 | 1 | 78L05 5V linear regulator | TO-92 | 78L05 | Motorobit | 78L05 | https://www.motorobit.com/78l05-voltaj-regulatoru-to92 | 3.0 | 3.0 | Island-side logic supply (15 V → 5 V).
C1 | 1 | 1000µF / 100V electrolytic | Radial | 1000µF/100V | Direnc.net | TBD | https://www.direnc.net/kondansatorler | 25.0 | 25.0 | DC-link bulk storage.
R1 | 1 | 100kΩ / 2W bleeder | Axial | 100k/2W | Direnc.net | TBD | https://www.direnc.net/direncler | 2.0 | 2.0 | Safety discharge path.
F1 | 1 | 15 A blade fuse + holder | Standard | 15A | Robotistan | TBD | https://www.robotistan.com/ | 8.0 | 8.0 | Short-circuit protection.
R2-R15 | 14 | 220Ω 1/4W 5% | Axial | R-220R-0.25W | Direnc.net | TBD | https://www.direnc.net/direncler | 0.3 | 4.2 | TLP250 LED limit (×8) + 6N137 LED (×6).
R16-R23 | 8 | 22Ω 1/4W 5% | Axial | R-22R-0.25W | Direnc.net | TBD | https://www.direnc.net/direncler | 0.3 | 2.4 | Gate series resistor (per MOSFET).
R24-R31 | 8 | 10kΩ 1/4W 5% | Axial | R-10K-0.25W | Direnc.net | TBD | https://www.direnc.net/direncler | 0.3 | 2.4 | Gate-source pull-down (per MOSFET).
C2-C31 | 30 | 100nF / 25V ceramic | THT | C-100nF | Direnc.net | TBD | https://www.direnc.net/kondansatorler | 0.5 | 15.0 | Decoupling on TLP250 + 6N137 + MCP3201 + B0515 + voltage divider + bypass.
C32-C35 | 4 | 10µF / 25V (per HS channel) | THT | C-10uF | Direnc.net | TBD | https://www.direnc.net/kondansatorler | 1.5 | 6.0 | Bootstrap energy storage on each high-side channel.
R32-R39 | 8 | 22Ω 2W wire-wound | Axial | R-22R-2W | Direnc.net | TBD | https://www.direnc.net/direncler | 1.5 | 12.0 | Snubber damping resistor (D-S of each MOSFET).
C36-C43 | 8 | 2.2nF / 630V film | Box | C-2n2-630V | Direnc.net | TBD | https://www.direnc.net/kondansatorler | 3.0 | 24.0 | Snubber capacitor (in series with the 22Ω 2W resistor).
R40-R41 | 2 | 1Ω 1/4W | Axial | R-1R0-0.25W | Direnc.net | TBD | https://www.direnc.net/direncler | 0.3 | 0.6 | B0515S current balancing (×2 parallels per bridge).
C44 | 1 | 100µF / 25V electrolytic | Radial | C-100uF | Direnc.net | TBD | https://www.direnc.net/kondansatorler | 1.0 | 1.0 | B0515S output filter.
R42 | 1 | 100kΩ 1% metal-film | Axial | R-100K-0.25W-1% | Direnc.net | TBD | https://www.direnc.net/direncler | 0.5 | 0.5 | Voltage divider — top (DC bus sense).
R43 | 1 | 5.1kΩ 1% metal-film | Axial | R-5K1-0.25W-1% | Direnc.net | TBD | https://www.direnc.net/direncler | 0.5 | 0.5 | Voltage divider — bottom.
R44-R46 | 3 | 4.7kΩ 1/4W | Axial | R-4K7-0.25W | Direnc.net | TBD | https://www.direnc.net/direncler | 0.3 | 0.9 | 6N137 output pull-up.
C45 | 1 | 1µF / 25V ceramic | THT | C-1uF | Direnc.net | TBD | https://www.direnc.net/kondansatorler | 1.0 | 1.0 | 78L05 input filter.
C46 | 1 | 10µF / 16V electrolytic | Radial | C-10uF-16V | Direnc.net | TBD | https://www.direnc.net/kondansatorler | 0.5 | 0.5 | 78L05 output filter.
R47 | 1 | 1kΩ 1/4W | Axial | R-1K0-0.25W | Direnc.net | TBD | https://www.direnc.net/direncler | 0.3 | 0.3 | ACS712 output divider — top.
R48 | 1 | 1.5kΩ 1/4W | Axial | R-1K5-0.25W | Direnc.net | TBD | https://www.direnc.net/direncler | 0.3 | 0.3 | ACS712 output divider — bottom.
J1-J3 | 3 | Screw terminal 2-pos 15A+ 5.08mm | PCB | XY-MT-508 | Direnc.net | TBD | https://www.direnc.net/konnektorler | 5.0 | 15.0 | 2× DC input + 1× AC output.
J4 | 1 | Pin header 2×10 (2.54mm male) | THT | 2x10-PIN | Direnc.net | TBD | https://www.direnc.net/konnektorler | 3.0 | 3.0 | Controller interface (signals to STM32 Nucleo).
HS1-HS4 | 4 | TO-220 clip-on heatsink | TO-220 | TO-220-HS | Robotistan | TBD | https://www.robotistan.com/ | 5.0 | 20.0 | MOSFET cooling.
W1 | 1 | 18 AWG silicone wire (red + black bundle) | 2m each | 18AWG-SI | Robotistan | TBD | https://www.robotistan.com/ | 30.0 | 30.0 | Power-stage wiring.
S1-S17 | 17 | DIP-8 IC turned-pin socket | DIP-8 | DIP-8-SKT | Direnc.net | TBD | https://www.direnc.net/entegre-soketleri | 1.5 | 25.5 | Sockets for TLP250 (×8) + 6N137 (×6) + MCP3201 (×3) per assembled module.

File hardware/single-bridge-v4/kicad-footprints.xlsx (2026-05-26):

Component | Value / Part # | Package | KiCad Footprint Path | Confidence | Notes
POWER SEMICONDUCTORS
IRFZ44N MOSFET | 55V, 49A, 17.5mΩ | TO-220-3 | Package_TO_SOT_THT:TO-220-3_Vertical | 100% | Standard KiCad lib. Pin order: Gate, Drain, Source. Also available: TO-220-3_Horizontal
TLP250 Optocoupler | Isolated gate driver | DIP-8 | Package_DIP:DIP-8_W7.62mm | 100% | Standard 300mil wide DIP-8. Pinout: 7.62mm row spacing
B0515S-1W DC-DC | 5V→15V, 1W isolated | SIP-4 | Converter_DCDC:Converter_DCDC_MORNSUN_B0505S-1W_SIP-4 (if available) or custom footprint from SnapEDA/Ultra Librarian | 50% | NOT in standard KiCad lib as of v8. MORNSUN SIP-4 body ~11.7×6mm, 4 pins at 2.54mm pitch. Download from SnapEDA or create custom. Pin pitch 2.54mm, pin 3 is NC on single-output version.
1N5408 Diode | 3A, 1000V | DO-201AD | Diode_THT:D_DO-201AD_P15.24mm_Horizontal | 100% | Standard KiCad lib. Also: D_DO-201AD_P12.70mm_Horizontal for tighter spacing
UF4007 Fast Diode | 1A, 1000V, 75ns | DO-41 | Diode_THT:D_DO-41_SOD81_P10.16mm_Horizontal | 100% | Standard KiCad lib. Same package as 1N4007. Also: P7.62mm variant
1.5KE62A TVS Diode | 53V standoff, 1500W | DO-201AD | Diode_THT:D_DO-201AD_P15.24mm_Horizontal | 100% | Same footprint as 1N5408 — both are DO-201AD package. Verify body size matches your specific supplier.
SENSING COMPONENTS
ACS712-20A Module | Hall-effect current sensor | Breakout module | Package_SO:SOIC-8_3.9x4.9mm_P1.27mm | 70% | If using the breakout module from Robotistan, just wire to 3-pin header. If placing bare IC on PCB, use SOIC-8 footprint from Sensor_Current lib.
MCP3201 ADC | 12-bit SPI ADC | DIP-8 | Package_DIP:DIP-8_W7.62mm | 100% | Standard 300mil DIP-8, same footprint as TLP250 body
6N137 Optocoupler | High-speed SPI isolation | DIP-8 | Package_DIP:DIP-8_W7.62mm | 100% | Standard 300mil DIP-8. Note pin 1 marker for correct orientation
78L05 Regulator | 5V/100mA | TO-92 | Package_TO_SOT_THT:TO-92_Inline | 100% | Standard KiCad lib. Check pinout order — 78L05 is Input-GND-Output (differs from 7805). Also: TO-92_Inline_Wide
POWER PASSIVES — DC BUS (per bridge ×2)
Electrolytic Cap | 1000µF / 100V | Radial, 18×35mm typical | Capacitor_THT:CP_Radial_D18.0mm_P7.50mm | 85% | Size depends on exact part. 1000µF/100V is typically 18mm dia. Check your part's datasheet. Could be D16.0 or D22.0 depending on brand.
Ceramic Cap (DC bus) | 100nF / 50V | Disc / Radial, 5mm pitch | Capacitor_THT:C_Disc_D5.0mm_W2.5mm_P5.00mm | 90% | Standard disc ceramic. Also try: C_Disc_D4.7mm_W2.5mm_P5.00mm. Check lead spacing on your part.
Bleeder Resistor | 100kΩ / 2W | Axial, ~15mm body | Resistor_THT:R_Axial_DIN0617_L17.0mm_D6.0mm_P20.32mm_Horizontal | 85% | 2W resistor body is ~6mm dia. Could also be DIN0516 (5mm dia). Check your part's physical size.
Blade Fuse + Holder | 15A automotive | PCB mount / panel | Fuse:Fuseholder_Blade_Mini_Keystone_3568 | 60% | Depends heavily on your specific holder. If using standard ATO blade fuse holder, check Fuse library. May need custom footprint or just wire in-line.
GATE DRIVE PASSIVES (×8 channels)
Resistor 220Ω | 1/4W, LED current limit | Axial | Resistor_THT:R_Axial_DIN0207_L6.3mm_D2.5mm_P10.16mm_Horizontal | 100% | Standard 1/4W axial resistor. Most common footprint in KiCad.
Resistor 22Ω (gate) | 1/4W, gate series | Axial | Resistor_THT:R_Axial_DIN0207_L6.3mm_D2.5mm_P10.16mm_Horizontal | 100% | Same footprint as all 1/4W resistors
Resistor 10kΩ | 1/4W, gate pull-down | Axial | Resistor_THT:R_Axial_DIN0207_L6.3mm_D2.5mm_P10.16mm_Horizontal | 100% | Same footprint as all 1/4W resistors
Ceramic Cap 100nF | 25V, TLP250 bypass | Disc / MLCC, 5mm pitch | Capacitor_THT:C_Disc_D5.0mm_W2.5mm_P5.00mm | 90% | Most common THT ceramic cap footprint. Could be P2.50mm if using smaller caps.
BOOTSTRAP COMPONENTS (×4 high-side channels)
UF4007 Fast Diode | Bootstrap charge diode | DO-41 | Diode_THT:D_DO-41_SOD81_P10.16mm_Horizontal | 100% | Already listed above — same footprint
Cap 10µF/25V | Bootstrap energy storage | Electrolytic or ceramic | Capacitor_THT:CP_Radial_D5.0mm_P2.50mm (electrolytic) or Capacitor_THT:C_Disc_D5.0mm_W2.5mm_P5.00mm (ceramic) | 85% | If electrolytic: 5mm dia is typical for 10µF/25V. If ceramic: standard disc. Check your actual part.
SNUBBER COMPONENTS (×8 MOSFETs)
Resistor 22Ω 2W | Snubber damping | Axial, larger body | Resistor_THT:R_Axial_DIN0617_L17.0mm_D6.0mm_P20.32mm_Horizontal | 85% | 2W body is larger than 1/4W. Could also be DIN0516 or DIN0414. Verify your part dimensions.
Film Cap 2.2nF/630V | Snubber cap | Box film, ~5mm pitch | Capacitor_THT:C_Rect_L7.2mm_W2.5mm_P5.00mm_FKS2_FKP2_MKS2_MKP2 | 75% | 630V film cap pitch varies: 5mm, 7.5mm, or 10mm depending on manufacturer. Measure your part's lead spacing. Try also: C_Rect_L7.0mm_W2.0mm_P5.00mm
ISOLATED SUPPLY PASSIVES (per bridge ×2)
Resistor 1Ω | 1/4W, B0515S balancing | Axial | Resistor_THT:R_Axial_DIN0207_L6.3mm_D2.5mm_P10.16mm_Horizontal | 100% | Standard 1/4W axial
Electrolytic Cap 100µF/25V | B0515S output filter | Radial | Capacitor_THT:CP_Radial_D6.3mm_P2.50mm | 90% | 100µF/25V is typically 6.3mm dia. Could be D5.0mm or D8.0mm. Check your part.
Ceramic Cap 100nF (supply) | HF bypass + B0515S input | Disc | Capacitor_THT:C_Disc_D5.0mm_W2.5mm_P5.00mm | 90% | Same as other 100nF ceramics
DC BUS SENSING PASSIVES (per island ×2)
Resistor 100kΩ 1% | Voltage divider upper | Axial, metal film | Resistor_THT:R_Axial_DIN0207_L6.3mm_D2.5mm_P10.16mm_Horizontal | 100% | Same physical size as standard 1/4W. Metal film just means tighter tolerance.
Resistor 5.1kΩ 1% | Voltage divider lower | Axial, metal film | Resistor_THT:R_Axial_DIN0207_L6.3mm_D2.5mm_P10.16mm_Horizontal | 100% | Same footprint
Resistor 220Ω (6N137) | LED current limit | Axial | Resistor_THT:R_Axial_DIN0207_L6.3mm_D2.5mm_P10.16mm_Horizontal | 100% | Same footprint as other 1/4W
Resistor 4.7kΩ | 6N137 output pull-up | Axial | Resistor_THT:R_Axial_DIN0207_L6.3mm_D2.5mm_P10.16mm_Horizontal | 100% | Same footprint
Ceramic Cap 100nF (sensing) | Bypass + divider filter | Disc | Capacitor_THT:C_Disc_D5.0mm_W2.5mm_P5.00mm | 90% | Same as other 100nF
Ceramic Cap 1µF/25V | 78L05 input filter | Disc or MLCC | Capacitor_THT:C_Disc_D5.0mm_W2.5mm_P5.00mm | 85% | 1µF ceramic may be slightly larger body. Check lead spacing.
Electrolytic Cap 10µF/16V | 78L05 output filter | Radial | Capacitor_THT:CP_Radial_D5.0mm_P2.50mm | 90% | Small electrolytic, typically 5mm dia. Could be 4mm on some brands.
CURRENT SENSING PASSIVES (safe side)
Resistor 1kΩ | Divider upper | Axial | Resistor_THT:R_Axial_DIN0207_L6.3mm_D2.5mm_P10.16mm_Horizontal | 100% | Standard 1/4W
Resistor 1.5kΩ | Divider lower | Axial | Resistor_THT:R_Axial_DIN0207_L6.3mm_D2.5mm_P10.16mm_Horizontal | 100% | Standard 1/4W
Ceramic Cap 100nF (current) | RC filter + ADC bypass | Disc | Capacitor_THT:C_Disc_D5.0mm_W2.5mm_P5.00mm | 90% | Same as other 100nF
CONNECTORS & MECHANICAL
Screw Terminal 2-pos (15A+) | DC inputs + AC output | 5.08mm pitch typical | TerminalBlock_Phoenix:TerminalBlock_Phoenix_MKDS-1,5-2-5.08_1x02_P5.08mm_Horizontal | 80% | 15A terminals are typically 5.08mm pitch. Could be 7.62mm for higher current. Check your specific terminal block. Also try: TerminalBlock_Phoenix_PT-1,5-2-5.0-H_1x02_P5.00mm
Pin Header 2×10 | Controller interface | 2.54mm pitch | Connector_PinHeader_2.54mm:PinHeader_2x10_P2.54mm_Vertical | 100% | Standard KiCad lib. 20-pin dual-row header.
Heatsink (TO-220) | MOSFET thermal management | Clip-on | Heatsink:Heatsink_Fischer_FK244_13AB01_25x13mm | 50% | Heatsink footprints are highly specific to the model you buy. This is a representative TO-220 clip-on. You may need to just add a courtyard zone in the PCB layout, or find your exact heatsink model.
CONFIDENCE LEGEND
100% | Exact match in standard KiCad library
85-90% | Very likely correct, minor size variation possible
70-80% | Footprint exists but you should verify pin spacing / body size
50-60% | Not in standard lib or highly dependent on specific part purchased. Custom footprint or download from SnapEDA/Ultra Librarian recommended.

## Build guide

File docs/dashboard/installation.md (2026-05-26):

# Installation

The dashboard targets **Python 3.11** specifically — `PySide6==6.5.3` (the pinned wheel) is built for Python 3.7–3.11 and does not yet have a 3.12 build.

## Fresh install (recommended — virtualenv)

```powershell
cd firmware/stm32-f303re
py -3.11 -m venv dashboard\.venv
dashboard\.venv\Scripts\python -m pip install --upgrade pip
dashboard\.venv\Scripts\python -m pip install -r dashboard\requirements.txt
```

Pinned versions (`dashboard/requirements.txt`):

```
PySide6==6.5.3
pyserial==3.5
pyqtgraph==0.13.7
numpy<2.0
```

## Run

```powershell
dashboard\.venv\Scripts\python dashboard\run_dashboard.py
```

## Troubleshooting

### `Unable to import Shiboken` or `DLL load failed`

The Qt stack didn't install cleanly. Rebuild the venv with the pinned versions:

```powershell
Remove-Item -Recurse -Force dashboard\.venv
py -3.11 -m venv dashboard\.venv
dashboard\.venv\Scripts\python -m pip install --upgrade pip
dashboard\.venv\Scripts\python -m pip install -r dashboard\requirements.txt
dashboard\.venv\Scripts\python dashboard\run_dashboard.py
```

If the same DLL error persists after a clean rebuild, install the latest **Microsoft Visual C++ Redistributable for x64**, then re-run the dashboard.

### Tests run but dashboard window is empty

`pyqtgraph` widgets need PySide6 to be the active Qt binding. If you have PyQt5 / PyQt6 installed system-wide, they can interfere. The venv-based install above isolates the right Qt — that's why it's recommended.

### Running the unit tests headless

The parser and simulator tests do **not** require PySide6, pyserial, or pyqtgraph and complete in under a second:

```powershell
cd firmware/stm32-f303re/dashboard
py -3 -m unittest discover tests -v
```

The Phase 1 `dashboard-tests` GitHub Actions workflow runs these on every push that touches the dashboard tree.

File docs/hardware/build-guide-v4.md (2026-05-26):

# 5-Level Cascaded H-Bridge Inverter — Build & Reference Guide v4.0

**Version 4.0 — May 2026 — As-built engineering reference**

ELE 401/402 Graduation Project — Hacettepe University, Department of Electrical & Electronics Engineering
Project Group "Cereyan Hacıları" — Furkan Emir Aksel · Ahmet Koçak · Faruk Gökhan Abay · Mücahit Aydın
Supervisor: Assoc. Prof. Dr. Rasım Doğan

---

## Document Status

This guide is the canonical engineering reference for the modular 5-Level Cascaded H-Bridge Inverter and the firmware that drives it. It supersedes **Build Guide v3.1** (February 2026) in its entirety.

v3.1 documented an earlier iteration (single dual-bridge PCB, IRFZ44N MOSFETs, IPD LS-PWM, 3-MISO sensing) with two pin-assignment errors and predates the final hardware architecture, modulation strategy, sensing topology, and operator dashboard. Where v4 disagrees with v3.1, **v4 is the authoritative reference** — see §13 for the errata.

This document describes what was actually fabricated, populated, bench-validated, and demonstrated:
- Two identical single-bridge PCB modules (4-layer, JLCPCB)
- IRFB4110 power MOSFETs
- PSC-PWM at 5 kHz, 5 distinct cascade output levels confirmed on oscilloscope
- Bridges thermally balanced under sustained load
- Bit-banged MCP3201 + 6N137 isolated sensing
- PySide6 desktop dashboard with full operator control

### Companion documents (firmware repository)

| Document | Purpose |
|---|---|
| `README.md` | Firmware overview and quick command reference |
| `CHANGELOG.md` | Design-decision history per release |
| `FIRST_BENCH_SESSION.md` | Linear walkthrough for first-time bring-up |
| `HARDWARE_BRINGUP.md` | Comprehensive phase-by-phase test procedure |
| `FSM_NOTES.md` | Control state machine diagram |
| `dashboard/README.md` | Dashboard installation and usage |

---

## Table of Contents

1. [System Overview](#1-system-overview)
2. [Architecture Decisions](#2-architecture-decisions)
3. [Hardware Bill of Materials](#3-hardware-bill-of-materials)
4. [Power Stage Detail](#4-power-stage-detail)
5. [Gate Drive Subsystem](#5-gate-drive-subsystem)
6. [Sensing Subsystem](#6-sensing-subsystem)
7. [Controller Interface](#7-controller-interface)
8. [Control Firmware](#8-control-firmware)
9. [PSC-PWM Modulation Explained](#9-psc-pwm-modulation-explained)
10. [Protection System](#10-protection-system)
11. [Dashboard & Operator Workflow](#11-dashboard--operator-workflow)
12. [Bring-Up & Test](#12-bring-up--test)
13. [V3.1 Errata](#13-v31-errata)
14. [Safety](#14-safety)
15. [Future Work](#15-future-work)

---

## 1. System Overview

The inverter converts two independent isolated DC sources into a single-phase AC output with a 5-level staircase waveform, suitable for cascaded grid-tie applications, photovoltaic energy harvesting, or stand-alone resistive loads. The cascaded multilevel topology produces lower harmonic distortion than a conventional two-level inverter, eliminates the need for an output transformer, and naturally supports series connection of independent DC sources.

### 1.1 Specifications

| Parameter | Value |
|---|---|
| Topology | Single-phase 5-Level Cascaded H-Bridge (CHB) |
| Power cells | 2 × full H-bridge, AC outputs in series |
| Per-bridge DC bus | 50 V nominal (5–60 V operating range) |
| Peak AC output | ±100 V (at MI = 0.95) |
| Continuous power | ~700 W into resistive load |
| Fundamental frequency | 50 Hz default (10–400 Hz configurable at runtime) |
| Switching frequency | 5 kHz (PSC, default); 100–20 000 Hz configurable |
| Modulation | Unipolar Phase-Shifted Carrier (PSC) SPWM, 90° between cells |
| Output levels | 5 (+2Vdc, +Vdc, 0, −Vdc, −2Vdc) — confirmed on bench |
| Dead-time | 3 µs (sized for IRFB4110) |
| Maximum duty | 95 % (firmware-enforced for bootstrap refresh) |
| Controller | STM32F303RE (Nucleo-F303RE, 64 MHz HSI/PLL) |
| Telemetry | NMEA-style ASCII over USART2/VCP @ 115 200 8N1, 20 Hz |
| Operator interface | PySide6 desktop dashboard, simulator + live serial sources |
| THD (simulated, no filter) | <5 % at 50 V bus, MI = 0.95 |

### 1.2 Modular Two-Board Architecture

The system is built as **two electrically identical single-bridge PCB modules** with their AC outputs connected in series:

```
       50 V Supply 1                          50 V Supply 2
             │                                       │
             │ (isolated)                            │ (isolated)
        ┌────▼─────────┐                       ┌────▼─────────┐
        │   Bridge 1   │                       │   Bridge 2   │
        │   (TIM1)     │                       │   (TIM8)     │
        │ Q1H Q1L Q2H Q2L│                     │Q3H Q3L Q4H Q4L│
        └─┬───────────┬─┘                       └─┬───────────┬─┘
          │ X1     Y1 │                           │ X2     Y2 │
          │           └─────── series tap ────────┘           │
          │           (Bridge 2 GND_HV floats here)           │
          │                                                   │
          └───────[ACS712]──────[ LOAD ]──────────────────────┘
                              AC output
```

Bridge 2's local DC negative (`GND_HV`) floats at Bridge 1's output node — **not** at system ground. Galvanic isolation between the two bridges' gate drives and sensing islands is therefore mandatory. This is the central electrical constraint of the design and dictates every isolation barrier choice that follows.

### 1.3 Power and Signal Domains

The system has four distinct electrical reference domains:

| Domain | Reference | Powered by | Purpose |
|---|---|---|---|
| `GND_System` | System ground | USB or external 5 V supply | STM32, dashboard interface |
| `GND_HV_B1` / `Drive_GND_B1` | Bridge 1 DC negative | Bridge 1 supply | Bridge 1 power stage and gate drive return |
| `GND_HV_B2` / `Drive_GND_B2` | Bridge 2 DC negative (floating) | Bridge 2 supply | Bridge 2 power stage and gate drive return |
| `GND_Island` (×2) | Local to each sensing island | 78L05 from +15V_Drive | MCP3201 ADC reference |

These domains connect only at their defined points: B0515S isolated DC-DC for the gate-drive supply crossover; TLP250 optocouplers for the gate-drive signal crossover; 6N137 optocouplers for the SPI crossover. Mixing them creates ground loops, measurement errors, and in the worst case, shoot-through.

---

## 2. Architecture Decisions

This section explains *why* the design looks the way it does. The reasoning matters as much as the schematic — future students or product engineers picking up the project need to understand the constraints that drove each choice.

### 2.1 Why Cascaded H-Bridge (not NPC or Flying-Capacitor)

Three multilevel topologies were considered:

| Topology | Pros | Cons | Decision |
|---|---|---|---|
| Neutral-Point Clamped (NPC) | Single DC source | Requires clamping diodes; capacitor-voltage balancing is non-trivial | Rejected |
| Flying Capacitor | Single DC source | Control complexity scales badly with level count | Rejected |
| Cascaded H-Bridge (CHB) | Modular, fault-tolerant, natural fit for independent PV sources | Requires N isolated DC sources for N+1 levels | **Selected** |

The CHB requirement for independent isolated DC sources is a natural match for photovoltaic strings and stacked battery banks, and is trivially satisfied on the bench with two laboratory power supplies.

### 2.2 Why IRFB4110 (not IRFZ44N or IGBTs)

The original v3.1 BOM specified IRFZ44N (55 V, 49 A, 17.5 mΩ). Bench experience and re-analysis identified two problems:

1. **Voltage headroom is insufficient.** At a 50 V steady-state bus, the IRFZ44N has only 5 V of margin to its 55 V V_DSS. The 1.5KE62A TVS clamps at 84.5 V — well above the IRFZ44N rating. A single transient could destroy the device.
2. **Modular re-spin cost was modest.** Moving to a 100 V class FET added pennies per device.

The IRFB4110 (100 V, 180 A, 4.5 mΩ) was selected as the replacement. The R_DS(on) reduction (17.5 mΩ → 4.5 mΩ) reduces conduction losses by ~4×, and the 100 V rating provides comfortable margin against the TVS clamp voltage.

IGBTs were considered and rejected for the operating point. At ~50 V and ~7 A, the IGBT's fixed V_CE(sat) (typically 1.5–2.5 V) dominates over MOSFET conduction losses. The cross-over current where IGBT becomes more efficient than the IRFB4110 is well above 85 A — far outside this project's operating range.

### 2.3 Why PSC-PWM (not LS-PWM)

v3.1 specified In-Phase Disposition Level-Shifted PWM (IPD LS-PWM). Bench testing of the earlier STAIR quantize-to-5-levels modulator revealed that the simpler approach — and IPD by extension — has an inherent **bridge-load asymmetry**: one bridge always carries the inner band (±1 step), the other only switches for the outer band (±2). This produced measurable thermal imbalance, with one of Bridge 1's MOSFETs running noticeably hotter than the rest.

Phase-Shifted Carrier (PSC) PWM resolves this structurally. With both cells running the same modulating reference against carriers offset by 360°/N (here 180°/2 = 90° per cell, or 180° between the two cells' carriers), each bridge handles an equal share of the switching workload. Output ripple frequency at the cascaded node doubles to 2·F_sw, which reduces filter requirements.

PSC was bench-validated against the requirement at the demo:
- ✅ 5 distinct cascade voltage levels visible on the oscilloscope without an LC filter
- ✅ Bridge 1 and Bridge 2 MOSFET case temperatures within ~3 °C at steady state
- ✅ No fault trips during sustained operation at the 50 V / 700 W design point

### 2.4 Why Two Identical Single-Bridge PCBs (not one dual-bridge PCB)

Earlier iterations placed both bridges on a single PCB. Three problems emerged:

1. **Repair cost.** A failure in one bridge required reworking the entire board.
2. **Isolation complexity.** Drawing both ground domains on one board made the isolation barrier visually ambiguous and easy to violate during layout edits.
3. **Reuse value.** A single-bridge module is also a useful standalone test fixture and a building block for higher-level inverters.

The modular approach uses two identical 4-layer PCBs. Each board has its own gate drive, its own sensing island, and its own connector to the controller. The only inter-board connection is the series AC output tap.

### 2.5 Why Bit-Banged MCP3201 + 6N137 (not analog op-amp sensing)

Bridge 2's DC bus must be measured at a potential that floats at Bridge 1's output node. Three options:

| Approach | Pros | Cons |
|---|---|---|
| Analog isolation amplifier (e.g., ISO124) | Continuous analog signal | Expensive, limited bandwidth, calibration drift |
| Differential resistor divider into MCU ADC | Cheap | Common-mode voltage exceeds ADC range at high bus |
| Digital ADC + optocoupler SPI return | Cheap parts, flexible, immune to common-mode | Requires careful SPI timing |

The third approach was selected. Each bridge has a local MCP3201 (12-bit single-channel SPI ADC) referenced to its own GND_Island, with the SPI lines crossing the isolation barrier through 6N137 optocouplers. Total parts per island: one MCP3201, three 6N137, one 78L05 — readily available, hand-solderable in DIP packages.

Hardware SPI peripheral usage was considered and rejected: the three MISO returns cannot be tri-stated cleanly (the 6N137 output stage doesn't release the line high-impedance), so bus-sharing the MISOs is not viable. Bit-banged GPIO SPI is used instead, with one shared SCK clocking all three ADCs while each MISO is read on its own GPIO pin.

### 2.6 Why VNOM-Derived Protection (not fixed thresholds)

Fixed protection thresholds sized for the 50 V design point trip immediately at any bench test below 40 V (the original UV threshold). This made low-voltage step-up testing impossible without disabling protection.

The firmware now derives the three voltage thresholds from a single runtime-configurable nominal bus voltage `VNOM`:

- UV = 0.80 × VNOM
- OV = 1.16 × VNOM
- IMBAL = 0.20 × VNOM

At VNOM = 50 the derived values reproduce the original 40 / 58 / 10 V design exactly. At VNOM = 12 (a typical low-voltage bench test) they become 9.6 / 13.9 / 2.4 V. The operator sets VNOM via UART or the dashboard before applying bus voltage.

The overcurrent threshold (`OC`) is independent of VNOM because it is a load property rather than a bus property.

---

## 3. Hardware Bill of Materials

All quantities below are **per single-bridge module**. The complete inverter uses two modules. Spare quantities are included in parentheses where applicable.

### 3.1 Per-Module Power Stage

| Component | Qty | Spec | Source |
|---|---|---|---|
| IRFB4110 MOSFET | 4 (+2) | TO-220, 100 V, 180 A, 4.5 mΩ | Motorobit / Direnc |
| TLP250 optocoupler | 4 (+1) | DIP-8, 1.5 A peak, 2 500 V_rms isolation | Motorobit |
| B0515S-1WR3 | 2 (+1) | SIP-4, 5 V→15 V, 1 W isolated | Motorobit |
| UF4007 | 2 (+2) | DO-41, 1 A, 75 ns recovery | Direnc |
| 1N5408 | 1 (+1) | DO-201, 3 A, 1 000 V | Direnc |
| 1.5KE62A | 1 (+1) | DO-201, 53 V standoff, 84.5 V clamp | Motorobit |
| 15 A blade fuse + holder | 1 (+1) | Automotive blade | Robotistan |

### 3.2 Per-Module Sensing

| Component | Qty | Spec | Source |
|---|---|---|---|
| MCP3201 ADC | 1 (+1) | DIP-8, 12-bit SPI, single channel | Direnc |
| 6N137 | 3 (+1) | DIP-8, 10 Mbit/s, photodiode + buffer | Direnc / Motorobit |
| ACS712-20A | 1 (+1) | SOIC-8, Hall-effect, 100 mV/A | Robotistan |
| 78L05 | 1 (+1) | TO-92, 5 V/100 mA LDO | Direnc |

The ACS712 is populated on both boards (footprint and current-path traces are mandatory in the AC output path) but the downstream signal conditioning is wired up only on the lower bridge. The `CS_EN` solder-bridge jumper on each board selects whether its MCP3201 current channel is connected to the SPI bus.

### 3.3 Per-Module Power Passives

| Component | Value | Qty | Role |
|---|---|---|---|
| Electrolytic capacitor | 1 000 µF / 100 V | 1 | DC link bulk storage |
| Ceramic capacitor | 100 nF / 100 V | 1 | DC bus HF bypass, near MOSFETs |
| Bleeder resistor | 100 kΩ / 2 W | 1 | Safety discharge for DC link cap |
| Film capacitor | 2.2 nF / 630 V | 4 | Snubber across each MOSFET D-S |
| Resistor | 22 Ω / 2 W | 4 | Snubber damping (in series with film cap) |

### 3.4 Per-Module Gate Drive Passives

| Component | Value | Qty | Role |
|---|---|---|---|
| Resistor | 220 Ω / 0.25 W | 4 | TLP250 LED current limit (controller side) |
| Resistor | 22 Ω / 0.25 W | 4 | MOSFET gate series resistor |
| Resistor | 10 kΩ / 0.25 W | 4 | MOSFET gate-source pull-down |
| Ceramic capacitor | 100 nF / 25 V | 4 | TLP250 VCC-GND bypass |
| UF4007 | 2 | DO-41 | Bootstrap charge diode (HS channels only) |
| Electrolytic capacitor | 10 µF / 25 V | 2 | Bootstrap energy storage (HS channels only) |

### 3.5 Per-Module Sensing Passives

| Component | Value | Qty | Role |
|---|---|---|---|
| Resistor | 100 kΩ / 1 % metal film | 1 | DC bus divider upper leg |
| Resistor | 5.1 kΩ / 1 % metal film | 1 | DC bus divider lower leg |
| Resistor | 220 Ω / 0.25 W | 3 | 6N137 LED current limit |
| Resistor | 4.7 kΩ / 0.25 W | 3 | 6N137 output pull-up |
| Ceramic capacitor | 100 nF / 25 V | 6 | Bypass: MCP3201, 6N137 (×3), 78L05 in/out filter |
| Ceramic capacitor | 1 µF / 25 V | 1 | 78L05 input filter |
| Electrolytic capacitor | 10 µF / 16 V | 1 | 78L05 output filter |
| Resistor (current path) | 1 kΩ / 0.25 W | 1 | ACS712 → ADC divider upper (lower bridge only) |
| Resistor (current path) | 1.5 kΩ / 0.25 W | 1 | ACS712 → ADC divider lower (lower bridge only) |
| Diagnostic LED | green 3 mm | 1 (DNP) | DC bus power indicator |
| Diagnostic LED | yellow 5 mm | 4 (DNP) | PWM activity per MOSFET channel |
| Diagnostic LED | red 5 mm | 1 (DNP) | Fault indication |

The diagnostic LEDs are populated as Do-Not-Place footprints — useful for debugging on the bench, omitted in normal operation to reduce part count.

### 3.6 Connectors

| Connector | Qty per board | Role |
|---|---|---|
| 2-position screw terminal, 15 A+ | 2 | DC input (+, −) and AC output |
| 2×10 pin header, 2.54 mm | 1 | Controller interface |
| TO-220 clip-on heatsink | 4 | MOSFET thermal management |

### 3.7 Supplier Strategy

The project sources all components from Turkish domestic suppliers to minimize lead time and shipping cost:

- **Motorobit** — integrated circuits, isolated DC-DC, MOSFETs
- **Direnc.net** — passives, MCP3201, 6N137, 78L05, diodes
- **Robotistan** — mechanical hardware, ACS712 modules, heatsinks
- **Komponentci.net** — connectors and additional passives

All SMD capacitors specified in v3.1 were converted to THT in v4 to ease hand soldering. The ACS712 remains SOIC-8 (the easiest SMD package for hand-assembly, and required to carry the wide AC current trace).

---

## 4. Power Stage Detail

Each bridge consists of four IRFB4110 MOSFETs arranged as a full H-bridge, with each leg's complementary pair driven through a TLP250 optocoupler.

### 4.1 H-Bridge Topology (per bridge)

```
                     Node_A (+50 V)
                  ┌──────┴──────┐
                  │             │
              ┌───┴───┐     ┌───┴───┐
              │ Q_H_L │     │ Q_H_R │   High-side MOSFETs
              │ (HS)  │     │ (HS)  │   (bootstrap driven)
              └───┬───┘     └───┬───┘
        Node_X───●               ●───Node_Y     AC output tap
                  │             │
              ┌───┴───┐     ┌───┴───┐
              │ Q_L_L │     │ Q_L_R │   Low-side MOSFETs
              │ (LS)  │     │ (LS)  │   (direct driven)
              └───┬───┘     └───┬───┘
                  └──────┬──────┘
                     GND_HV
              (= local Drive_GND for this bridge)
```

The bridge's AC output is `Node_X − Node_Y`. Each MOSFET has an associated snubber (22 Ω 2 W + 2.2 nF / 630 V in series) across its drain-source to damp turn-off ringing.

### 4.2 DC Input Protection Chain

Five components in parallel between `Node_A` and `GND_HV`:

| Element | Wiring | Function |
|---|---|---|
| 1N5408 diode | Cathode to Node_A, anode to GND_HV | Reverse-polarity protection (conducts on reverse, blows the fuse) |
| 1.5KE62A TVS | Cathode to Node_A, anode to GND_HV | Transient clamp at 84.5 V max (within IRFB4110's 100 V rating) |
| 1 000 µF / 100 V electrolytic | + to Node_A, − to GND_HV | Bulk energy storage for switching transients |
| 100 nF / 100 V ceramic | Across Node_A and GND_HV, near MOSFETs | High-frequency bypass |
| 100 kΩ / 2 W bleeder | Across Node_A and GND_HV | Discharges DC link cap after power-off (~8 min to safe voltage) |

A 15 A blade fuse sits in series with the (+) input terminal upstream of all the above.

**WARNING:** Bridge 2's `GND_HV` is **not** system ground. It floats at the series tap. Never tie the two bridges' `GND_HV` nodes together.

---

## 5. Gate Drive Subsystem

The gate drive must:
- Switch four MOSFETs per bridge with adequate dead-time
- Provide galvanic isolation between the controller and each MOSFET source (mandatory for high-side switching on a floating bridge)
- Maintain its own +15 V supply referenced to the bridge's local Drive_GND

### 5.1 Isolated +15 V Generation (per bridge)

Two B0515S-1W modules are paralleled per bridge, producing a combined 2 W output rail:

```
System +5 V ──┬── B0515S_A pin 2 (V_in+)       100 nF bypass cap on each
              └── B0515S_B pin 2 (V_in+)       module's input

System GND ───┬── B0515S_A pin 1 (V_in−)
              └── B0515S_B pin 1 (V_in−)
              ════ isolation barrier ════

B0515S_A pin 4 ─ 1 Ω ─┐
B0515S_B pin 4 ─ 1 Ω ─┴── +15V_Drive (per bridge)
                          + 100 µF/25 V electrolytic
                          + 100 nF ceramic

B0515S_A pin 3 ─┐
B0515S_B pin 3 ─┴── Drive_GND (= bridge low-side MOSFET sources)
```

The 1 Ω balancing resistors force current sharing between the two unregulated modules. At a typical 50 mA combined load the drop across each is only 25 mV. Total gate-drive supply load per bridge is approximately 0.75–1.25 W (4 TLP250s + 78L05 island regulator), well within the paralleled 2 W capacity.

### 5.2 TLP250 Gate Driver (per MOSFET)

Pinout and per-MOSFET wiring:

| Pin | Name | Connection |
|---|---|---|
| 1 | N/C | unconnected |
| 2 | LED anode | Controller PWM pin → 220 Ω → pin 2 |
| 3 | LED cathode | `GND_System` (controller side) |
| 4 | N/C | unconnected |
| 5 | GND (driver side) | See §5.3 / §5.4 below |
| 6 | V_out | → 22 Ω → MOSFET gate |
| 7 | V_out (inverted) | Tie to pin 5 through 10 kΩ for noise immunity, or leave open |
| 8 | VCC | See §5.3 / §5.4 below |

A 100 nF ceramic bypass capacitor sits across pin 8 and pin 5 of every TLP250, placed as close to the IC as physically possible. **This is the single most important gate-drive layout detail.** A long bypass path causes 5 kHz oscillation and rapid TLP250 thermal failure.

Per-MOSFET gate circuit:
- TLP250 pin 6 → 22 Ω → MOSFET gate (limits peak gate current to ~0.68 A)
- MOSFET gate → 10 kΩ → MOSFET source (pull-down, ensures OFF during power-up)
- MOSFET drain-source: 22 Ω 2 W + 2.2 nF / 630 V in series (snubber)

LED input current is set by the 220 Ω resistor: (3.3 V − 1.2 V) / 220 Ω = 9.5 mA, within the TLP250's 5–16 mA reliable operating range.

### 5.3 Low-Side TLP250 (Q_L_L and Q_L_R, ×2 per bridge)

The low-side MOSFETs' sources are tied to the bridge's `Drive_GND`. Their TLP250 drivers connect directly:

- Pin 8 (VCC) → `+15V_Drive` rail
- Pin 5 (GND) → `Drive_GND`

### 5.4 High-Side TLP250 with Bootstrap (Q_H_L and Q_H_R, ×2 per bridge)

High-side MOSFETs' sources switch between `Drive_GND` (when the low-side of that leg is ON) and `+50V` (when the high-side is ON). The TLP250 driving the high-side must "ride" this switching node, which requires a bootstrap supply:

```
+15V_Drive ──┬── UF4007 anode    The UF4007 conducts when V_switch is low,
             │                   charging the 10 µF bootstrap cap to ~14.3 V.
             │   UF4007 cathode  When V_switch goes high, the diode reverse-
             ●── Node_Boot       biases and the cap floats with the source.
             │
             │   10 µF/25 V cap
             │ ── + terminal
             │
             │
HS MOSFET    │
source ──────┼── Node_VS (switching node)
             │ ── − terminal of 10 µF cap

TLP250 pin 8 (VCC) ── Node_Boot
TLP250 pin 5 (GND) ── Node_VS  (= MOSFET source)
TLP250 pin 5–8 bypass: 100 nF as close to IC as possible
```

How the bootstrap works:
1. When the low-side of that leg is ON, the switching node is pulled to `Drive_GND` (≈ 0 V). The UF4007 forward-biases. The 10 µF cap charges to ~14.3 V (15 V minus 0.7 V diode drop).
2. When the high-side turns ON, the switching node rises to +50 V. The UF4007 reverse-biases (blocks). The cap provides a floating 14.3 V supply to the TLP250.
3. The cap discharges through the TLP250's quiescent current (~16 mA). At 95 % duty cycle at 5 kHz, on-time = 190 µs, so droop = (16 mA × 190 µs) / 10 µF = 0.3 V. The TLP250's 10 V minimum is easily maintained.
4. On the next low-side ON period the cap recharges.

**WARNING:** Maximum duty cycle 95 %. At 100 % duty the low-side never turns ON, the bootstrap cap never recharges, and high-side drive collapses. The firmware enforces this clamp.

### 5.5 Bootstrap Pre-Charge

At power-up all bootstrap caps are uncharged. The firmware runs a 6 ms pre-charge sequence at every START: both bridges' low-side MOSFETs are turned fully ON, both high-sides fully OFF. This charges all four bootstrap caps before normal modulation begins.

### 5.6 Dead-Time Selection

Dead-time is set to **3 µs** for the IRFB4110 power stage. The IRFB4110 has roughly 2× the gate charge of the IRFZ44N (~150 nC vs ~67 nC), so with the same 22 Ω gate series resistor the turn-on/turn-off transitions take about twice as long. The OLD bench-validated 2 µs (sized for IRFZ44N) no longer leaves enough shoot-through margin.

The dominant term remains the TLP250 propagation delay (0.5 µs typical, 1.5 µs maximum), which is independent of the MOSFET choice.

At 5 kHz switching, 3 µs is 1.5 % of the period — negligible output amplitude impact.

The dead-time is encoded in the STM32 advanced timer's `BDTR.DTG` register as `0xA0` (corresponds to `TIM_DTG_3US_AT_64MHZ` in the firmware).

---

## 6. Sensing Subsystem

The sensing subsystem measures three quantities and reports them to the controller:
- Bridge 1 DC bus voltage (isolated, on Bridge 1's PCB)
- Bridge 2 DC bus voltage (isolated, on Bridge 2's PCB)
- AC output current (safe-side, on the lower bridge's PCB)

### 6.1 Isolated Sensing Island Architecture

Each bridge PCB hosts a self-contained sensing island powered from the local +15 V_Drive rail through a 78L05 regulator:

```
+15V_Drive ─ 1 µF ─┬─ 78L05 IN ─ 78L05 OUT ─┬─ +5V_Island
                   │                          │
                   │   78L05 GND              ├─ 100 nF ceramic
                   │                          ├─ 10 µF/16 V electrolytic
                   │                          │
                   │                          ▼
Drive_GND ─────────┼──────────────────── GND_Island
```

78L05 dissipation: (15 V − 5 V) × 25 mA ≈ 0.25 W, easily handled by the TO-92 package without a heatsink.

The +5V_Island rail powers the MCP3201's VDD (which is also its analog reference) and the output side of the three 6N137 optocouplers.

### 6.2 DC Bus Voltage Divider (per bridge)

```
Node_A (+50 V) ── 100 kΩ ──●── 5.1 kΩ ── GND_Island
                            │
                            ├── 100 nF (noise filter)
                            │
                            └── MCP3201 pin 2 (IN+)
                                MCP3201 pin 3 (IN−) ── GND_Island
```

At 50 V input: divider output = 50 × 5.1 / 105.1 ≈ 2.42 V, using 48 % of the ADC's 0–5 V range. At 60 V (OV threshold + margin): 2.91 V — still safely within range.

Resolution: 50 V / (4096 × 0.0485) ≈ 0.252 V per ADC count.

### 6.3 ACS712 Current Path (lower bridge only)

The ACS712 is wired in series with the AC output:

```
Bridge 1 X1 ── [load wire] ── ACS712 IP+ ── ACS712 IP− ── [load wire] ── Bridge 2 Y2
                                  │
                                  └── OUT (2.5 V at zero current, ±100 mV per A)

ACS712 OUT ── 1 kΩ ── ADC_Node ── 1.5 kΩ ── GND_System
                          │
                          └── 100 nF (RC filter, f_c ≈ 1.6 kHz)
                          └── MCP3201 (current) pin 2 (IN+)
```

Divider ratio 1.5 / (1 + 1.5) = 0.6. At zero current: 2.5 × 0.6 = 1.5 V at ADC. At ±20 A (sensor max): 2.7 V or 0.3 V. Comfortably within the safe-side MCP3201's 0–3.3 V range.

### 6.4 MISO Topology — Two Lines, Not Three

**This is the single most important departure from v3.1.** v3.1 specified three independent MISO returns (one per ADC, each through its own 6N137). The built hardware uses **two** physical MISO return lines:

| MISO line | Carries | Reason |
|---|---|---|
| `MISO_DC1` (STM32 PA6) | Lower-bridge DC ADC only | Lower-bridge island has its own isolated MISO |
| `MISO_DC2` / `MISO_CUR` (STM32 PC3) | Upper-bridge DC ADC **and** the current ADC | Wire-shared on the upper-bridge island |

Because the DC2 and CUR ADCs share one wire on the upper island, the firmware must read them **sequentially, one chip-select at a time** — never both selected together. The bit-banged SPI driver enforces this with a single-channel read loop.

This change cuts down on a 6N137 per system, simplifies the upper-bridge island layout, and matches what is electrically tractable on a hand-built breadboard.

### 6.5 6N137 SPI Isolation (3 per island)

The 6N137 is a 10 Mbit/s photodiode + buffer optocoupler with an active-low output (LED ON → output LOW). Each line crosses one 6N137:

| Line | Direction | LED side | Output side |
|---|---|---|---|
| SCK | Controller → island | Controller PA5 → 220 Ω → 6N137 pin 2 | 6N137 pin 6 → 4.7 kΩ → +5V_Island; pin 6 → MCP3201 CLK |
| CS | Controller → island | Controller PC0/PC1/PC2 → 220 Ω → 6N137 pin 2 | 6N137 pin 6 → 4.7 kΩ → +5V_Island; pin 6 → MCP3201 CS |
| MISO | Island → controller | MCP3201 DOUT → 220 Ω → 6N137 pin 2 | 6N137 pin 6 → 4.7 kΩ → +3.3V (controller side); pin 6 → STM32 MISO pin |

Each 6N137 has 100 nF bypass across pins 5 and 8, and pin 7 (enable) tied permanently low (enabled).

**The 6N137 inverts.** Without compensation, the MCP3201 sees an inverted clock, an inverted (high-when-active) chip-select, and inverted data. The firmware handles this with the runtime-configurable `SPIINV` mask (see §8.7).

### 6.6 SPI Timing

The bit-banged SPI runs at ~140 kHz (limited by the volatile-loop half-period delay). The MCP3201's 1.6 MHz absolute maximum is comfortably honored. The 6N137 round-trip propagation delay (~150 ns) is well below the half-period at this speed.

For higher sense rates a hardware SPI peripheral could be added later, but at the current 1 kHz scan rate (60 µs read time × 3 sequential channels = 180 µs total) there is no benefit.

---

## 7. Controller Interface

The STM32F303RE Nucleo board connects to the two bridges through a single 2×10 header (2.54 mm pitch) on each PCB.

### 7.1 STM32 Pin Map (As Built — Supersedes v3.1)

| Signal | STM32 pin | Alternate function | Role |
|---|---|---|---|
| PWM_1H | **PA8** | TIM1_CH1 (AF6) | Bridge 1, Q_H_L (high-side, left leg) |
| PWM_1L | **PA7** | TIM1_CH1N (AF6) | Bridge 1, Q_L_L (low-side, left leg) |
| PWM_2H | **PA9** | TIM1_CH2 (AF6) | Bridge 1, Q_H_R (high-side, right leg) |
| PWM_2L | **PA12** | TIM1_CH2N (AF6) | Bridge 1, Q_L_R (low-side, right leg) |
| PWM_3H | **PB6** | TIM8_CH1 (AF5) | Bridge 2, Q_H_L |
| PWM_3L | **PB3** | TIM8_CH1N (AF4) | Bridge 2, Q_L_L |
| PWM_4H | **PB8** | TIM8_CH2 (AF10) | Bridge 2, Q_H_R |
| PWM_4L | **PB0** | TIM8_CH2N (AF4) | Bridge 2, Q_L_R |
| SCK (shared) | **PA5** | GPIO output | MCP3201 SPI clock, bit-banged |
| CS_DC1 | **PC0** | GPIO output | Lower bridge DC ADC chip-select |
| CS_DC2 | **PC1** | GPIO output | Upper bridge DC ADC chip-select |
| CS_CUR | **PC2** | GPIO output | Current ADC chip-select |
| MISO_DC1 | **PA6** | GPIO input | Lower bridge DC ADC data (own line) |
| MISO_DC2 / MISO_CUR | **PC3** | GPIO input | Upper bridge DC ADC + current ADC data (shared line) |
| FAULT_OUT | **PB5** | GPIO output | Active-low hardware fault indicator |
| USART2_TX | **PA2** | USART2_TX (AF7) | ST-LINK VCP transmit |
| USART2_RX | **PA3** | USART2_RX (AF7) | ST-LINK VCP receive |

**This pin map differs from v3.1 in two important places** — see §13 for the errata.

### 7.2 Power Supply Inputs

| Supply | Voltage | Current | Purpose |
|---|---|---|---|
| Bridge 1 DC input | 50 V (5–60 V tested) | 0–15 A | Bridge 1 power stage |
| Bridge 2 DC input | 50 V (5–60 V tested) | 0–15 A | Bridge 2 power stage |
| System 5 V | 5.0 V ± 0.25 V | ≤ 1.2 A | B0515S inputs + ACS712 + safe-side MCP3201 |
| USB | 5 V | ≤ 0.2 A | Nucleo via ST-LINK |

The system 5 V can alternatively be derived from Bridge 1's 50 V bus through an LM2596 buck module — useful for portable demos that reduce the supply count to two.

### 7.3 Header Pinout (per board)

| Pin | Signal | Direction | Notes |
|---|---|---|---|
| 1 | PWM_1H (board 1) / PWM_3H (board 2) | In | From TIM1_CH1 or TIM8_CH1 |
| 2 | PWM_1L (board 1) / PWM_3L (board 2) | In | From TIM1_CH1N or TIM8_CH1N |
| 3 | PWM_2H / PWM_4H | In | |
| 4 | PWM_2L / PWM_4L | In | |
| 5 | SCK | In | Shared 1 MHz max bit-bang clock |
| 6 | CS (this board's DC ADC) | In | |
| 7 | CS_CUR (lower board only) | In | Only used on board with CS_EN populated |
| 8 | MISO (this board) | Out | Through 6N137, pulled up to controller I/O voltage |
| 9 | FAULT_OUT | Out | Active-low hardware fault |
| 10 | +5 V_System | Power | |
| 11 | +3.3 V (controller I/O ref) | Power | For MISO 6N137 output pull-up |
| 12 | GND_System | Power | |
| (unused pins) | reserved | | |

The two boards are wired identically. Differentiation between "Bridge 1" and "Bridge 2" is purely which timer drives that board (TIM1 vs TIM8) and which DC source feeds it.

---

## 8. Control Firmware

The firmware is a CMSIS bare-metal implementation on the STM32F303RE running at 64 MHz from the internal HSI through the PLL (no external crystal). Build artifacts: ~36 KB Flash, ~4 KB RAM.

### 8.1 State Machine

```
                  sensor fault / UV / OV / OC / imbalance
 BOOT ──▶ IDLE ─────────────────────────────────────────┐
          │                                              │
          │ START                                        ▼
          ▼                                         ┌─────────┐
       PRECHARGE ── precharge_done ──▶ RUN ─ fault ─▶  FAULT  │
          │                            │              └─────────┘
          │ STOP                       │ STOP             │
          ▼                            ▼                  │ CLEAR
        IDLE  ◀───────────────────── IDLE ◀───────────────┘
```

- **BOOT** initializes hardware, runs the ADC self-test, chooses the most capable available sensing mode, drops to IDLE.
- **IDLE** keeps both timers' MOE bits low (all gates off), accepts commands.
- **PRECHARGE** enables MOE and runs the 6 ms bootstrap pre-charge sequence (both LS on, both HS off).
- **RUN** runs the active modulator and checks protection after each 1 kHz sensor scan.
- **FAULT** clears MOE, latches the fault bits, drives FAULT_OUT low, requires CLEAR after the active condition is gone.

### 8.2 Sensing Modes

Six modes with graceful boot-time degradation:

| ID | Mode | Sensors used | Active protection |
|---|---|---|---|
| 0 | `FULL` | DC1, DC2, current | UV, OV, OC, imbalance |
| 1 | `DC_ONLY` | DC1, DC2 | UV, OV, imbalance |
| 2 | `CUR_ONLY` | Current | OC |
| 3 | `OPEN` | None | None (warns operator) |
| 4 | `DC1` | DC1, optional current | DC1 UV/OV + OC if available |
| 5 | `DC2` | DC2, optional current | DC2 UV/OV + OC if available |

At boot, each MCP3201 is read four times. Sensors stuck at 0x000 or 0xFFF are marked unavailable. The FSM auto-demotes to the most capable supported mode.

### 8.3 Modulators

Three modulators are selectable at runtime:

| Modulator | Switching freq | Bridges | Output | Status |
|---|---|---|---|---|
| `STAIR` | 500 Hz | Bridge 1 carries ±1 | 5-level staircase | Reliable, thermally unbalanced (legacy) |
| `STAIR_ALT` | 500 Hz | ±1 ownership alternates | 5-level staircase | Reliable, thermally balanced |
| `PSC` | 5 kHz default | Both bridges modulated | True 5-level PWM | **Default in v4** — project deliverable |

Switching is via the UART `MOD STAIR|PSC|STAIR_ALT` command or the dashboard's modulator dropdown.

The boot-default modulator is set by the `PWM_DEFAULT_MODULATOR` macro in `Core/Inc/pwm_config.h`.

### 8.4 Auto-Start

If no UART byte is received within 3 seconds of boot, the firmware issues its own START using the configured defaults. Any UART byte cancels auto-start permanently. The dashboard exploits this by sending `STATUS` on connect (and on every detected `$A,BOOT_SELF_TEST_DONE` line for post-reset cancellation), so a connected dashboard always retains full operator control.

This auto-start mechanism enables standalone deployment — the inverter runs from defaults with USB power only, no PC required.

### 8.5 Interrupt Hierarchy

| IRQ | Priority | Purpose |
|---|---|---|
| TIM1_UP (PWM update) | 0 (highest) | Per-period modulator dispatch, CCR write |
| TIM6 (sense tick) | 2 | 1 kHz flag-set only; SPI read happens in main loop |
| USART2 | 3 | Per-byte RX, TX buffer drain |
| SysTick | 15 (lowest) | ms counter |

This priority ordering guarantees PWM timing is never delayed by sensing or communication.

### 8.6 Telemetry Format

Telemetry emits at 20 Hz over USART2 in NMEA-style ASCII lines with XOR checksums:

```
$T,<ms>,<state>,<mode>,<fault>,<vdc1>,<vdc2>,<iout>,<level>*<chk>
```

Example: `$T,12345,RUN,FULL,0x00,49.87,50.02,3.41,1*7B`

Other line prefixes:

| Prefix | Type | Example |
|---|---|---|
| `$A,` | Acknowledgment | `$A,START` |
| `$E,` | Error | `$E,MODE_SENSOR_UNAVAILABLE` |
| `$F,` | Fault report | `$F,0x09,UV\|IMBAL` |
| `$H,` | Help text | `$H,START STOP CLEAR ...` |
| `$S,` | Status snapshot | `$S,ms=42,state=IDLE,mode=FULL,fault=0x00,...` |
| `$C,` | PWM config | `$C,mod=PSC,fsw=5000,bridge=BOTH,ffund=50.00,mi=0.95,cntoff=3199,lock=OK` |
| `$P,` | Protection config | `$P,vnom=50.00,uv=40.00,ov=58.00,oc=15.00,imbal=10.00` |
| `$R,` | Raw ADC diagnostic | `$R,dc1=2017,dc2=2018,cur=1862` |

### 8.7 UART Command Reference

| Command | Allowed states | Action |
|---|---|---|
| `START` | IDLE | Enable MOE, enter PRECHARGE then RUN |
| `STOP` | PRECHARGE, RUN | Disable MOE, return to IDLE |
| `CLEAR` | FAULT | Clear latched fault if active condition is gone |
| `MODE <0..5>` | IDLE, FAULT | Select sensing mode |
| `STATUS` | Any | Print one `$S` status line |
| `HELP` | Any | Print full command list |
| `MI <0.0..0.95>` | IDLE | Set modulation index |
| `RESCAN` | IDLE, FAULT | Re-run ADC self-test, re-mark sensors |
| `MOD STAIR\|PSC\|STAIR_ALT` | IDLE | Select modulator |
| `FSW <hz>` | IDLE | Set switching frequency (100–20 000 Hz) |
| `BRIDGE BOTH\|B1\|B2` | IDLE | Single-bridge test mode |
| `FFUND <hz>` | IDLE | Set fundamental frequency (10–400 Hz) |
| `VNOM <v>` | IDLE, FAULT | Set nominal bus voltage (derives UV/OV/IMBAL) |
| `OC <a>` | IDLE, FAULT | Set overcurrent threshold (0.5–20 A) |
| `SPIINV <0..7>` | IDLE, FAULT | Set MCP3201 SPI line-inversion mask + auto-rescan |
| `ADCRAW` | Any | One-shot raw MCP3201 read for diagnostics |
| `TRIP` | IDLE, PRECHARGE, RUN | Operator-forced fault — for demo purposes |
| `CONFIG` | Any | Print `$C` and `$P` config lines |

### 8.8 SPIINV — The 6N137 Polarity Switch

Each MCP3201 SPI line crosses a 6N137 optocoupler, which inverts. The firmware can be told to drive/read each line inverted to cancel the optocoupler:

| Bit | Line | When to set |
|---|---|---|
| 0 (0x01) | SCK | Wired through one 6N137 (standard) |
| 1 (0x02) | CS | Wired through one 6N137 (standard) |
| 2 (0x04) | MISO | Wired through one 6N137 (standard) |

For the standard wiring (one 6N137 per line), set `SPIINV 7`. For direct (non-isolated) test wiring, `SPIINV 0`. Other values handle mixed topologies during diagnostic work.

Setting SPIINV also automatically re-runs the ADC self-test so the operator immediately sees whether sensors come alive at the new polarity.

The boot default is set by `SPI_DEFAULT_INVERT_MASK` in `Core/Inc/spi_mcp3201.h`.

---

## 9. PSC-PWM Modulation Explained

### 9.1 Principle

In phase-shifted carrier PWM (PSC), each H-bridge cell modulates the same reference sine against its own triangular carrier, with the carriers offset in phase between cells. For N cascaded cells the carriers are spaced 360°/N apart (or equivalently 180°/N for natural cancellation).

For this two-cell system (N = 2), the carriers are 90° apart. The cascaded output waveform exhibits:
- Switching ripple at 2 × F_sw (10 kHz here), naturally cancelling at the cascade tap
- 5 distinct voltage levels (+2Vdc, +Vdc, 0, −Vdc, −2Vdc) over each sine peak region
- Balanced switching load between bridges (each switches at F_sw)

The 5-level output is intrinsic to PSC with 90° carrier shift; no quantization logic in software is required.

### 9.2 Unipolar Switching per Bridge

Within each H-bridge, the two legs are driven complementarily with opposite phase modulating signals:
- Leg A: duty = 0.5 + 0.5 × ref (where `ref` is the sine reference in range [−1, +1])
- Leg B: duty = 0.5 − 0.5 × ref

This produces a unipolar PWM output between the leg outputs, with effective switching frequency at the bridge output of 2 × F_sw. Combined with the 90° carrier shift between bridges, the cascaded output ripple is at 4 × F_sw.

### 9.3 STM32 Implementation

Both TIM1 (Bridge 1) and TIM8 (Bridge 2) are advanced-control timers configured for center-aligned PWM with complementary outputs and 3 µs dead-time. They share the APB2 timer clock at 64 MHz.

At a 5 kHz target switching frequency, the timer ARR is:
```
ARR = TIMER_CLK / (F_sw × 2) − 1 = 64 000 000 / (5 000 × 2) − 1 = 6 399
```

(The factor of 2 accounts for center-aligned mode, where one PWM period equals 2 × ARR counter ticks.)

The 90° phase shift between TIM8 and TIM1 is implemented by preloading TIM8's counter to `ARR / 2 = 3 199` ticks ahead of TIM1, immediately after both timers' CEN bits are set:

```c
TIM1->CR1 |= TIM_CR1_CEN;
TIM8->CR1 |= TIM_CR1_CEN;
if (g_pwm_modulator == MODULATOR_PSC) {
    TIM8->CNT = g_pwm_period / 2u;  // 90° offset for N=2
}
```

Because both timers share the same clock domain, once the offset is established it remains locked indefinitely. No master-slave timer linkage is required.

### 9.4 Phase-Lock Diagnostic

After applying a new PSC configuration the firmware reads both counters back, computes the measured offset, and reports it in the `$C` config line:

```
$C,mod=PSC,fsw=5000,bridge=BOTH,ffund=50.00,mi=0.95,cntoff=3200,lock=OK
```

`cntoff` is the measured TIM8 − TIM1 counter offset in clock ticks. `lock=OK` if the measured value is within 5 % of the expected ARR/2; `lock=BAD` otherwise. The operator (or dashboard) sees instantly whether the 90° shift took effect — without needing to scope two timers simultaneously.

### 9.5 Sine Look-Up Table

The reference sine is generated from a 256-entry pre-computed LUT. At each PWM update interrupt the phase accumulator is advanced by:

```
phase_increment = (F_fundamental / F_sw) × 256_samples
```

At 50 Hz fundamental and 5 kHz switching: 25.6 samples per PWM period. The accumulator is a `float` for sub-sample precision; the integer index into the LUT truncates the fractional part.

---

## 10. Protection System

The firmware implements seven fault conditions, all with software response. Hardware fuses provide the last line of defense.

### 10.1 Fault Categories

| Fault | Detection | Default threshold (VNOM=50 V) | Response |
|---|---|---|---|
| Undervoltage (UV) | DC bus < 0.80 × VNOM | 40 V | Latch, drop MOE |
| Overvoltage (OV) | DC bus > 1.16 × VNOM | 58 V | Latch, drop MOE |
| Overcurrent (OC) | \|I_out\| > OC threshold | 15 A | Latch, drop MOE |
| Imbalance | \|V_DC1 − V_DC2\| > 0.20 × VNOM | 10 V | Latch, drop MOE |
| Sensor lost | 5 consecutive 0x000 or 0xFFF reads | — | Latch, drop MOE |
| Manual TRIP | Operator command | — | Latch, drop MOE |
| Hardware short circuit | 15 A blade fuse | — | Physical disconnect |

### 10.2 Debounce

Each voltage/current fault uses a 3-sample N-of-M debounce at the 1 kHz sense rate. The fault must be observed in 3 consecutive scans before it trips. Single-sample noise is rejected; legitimate faults trip within ~3 ms.

### 10.3 FAULT_OUT Hardware Pin

PB5 is configured as a push-pull GPIO output, active-low. When the FSM latches any fault, FAULT_OUT is driven LOW; on return to IDLE it returns HIGH. This pin is intended to drive an external interlock relay or status LED. It corresponds to v3.1 header pin 16.

### 10.4 Clearing Faults

The `CLEAR` command is accepted only in FAULT state and only if the underlying condition has cleared. The firmware re-evaluates protection at the moment of CLEAR; if any fault bit is still active, CLEAR is rejected with `$E,FAULT_STILL_ACTIVE`. This prevents the operator from inadvertently re-enabling power into a still-failed condition.

---

## 11. Dashboard & Operator Workflow

The PC dashboard is the primary operator interface. It runs on Windows, Linux, and macOS, requires no firmware modification, and exposes every UART command through tappable controls.

### 11.1 Architecture

```
┌─────────────────────────┐         ┌──────────────────────────┐
│  STM32F303RE Nucleo     │         │   PySide6 Dashboard      │
│  ┌────────────────────┐ │   USB   │  ┌─────────────────────┐ │
│  │  Firmware FSM      │ │   VCP   │  │  Source Adapter     │ │
│  │  + PSC modulator   │ │ ─────── │  │  (Serial / Sim /    │ │
│  │  + Sensing         │ │ 115200  │  │   Replay)           │ │
│  │  + Protection      │ │   8N1   │  └─────────────────────┘ │
│  │  + USART2 telem    │ │         │  ┌─────────────────────┐ │
│  └────────────────────┘ │         │  │  NMEA Parser        │ │
└─────────────────────────┘         │  └─────────────────────┘ │
                                    │  ┌─────────────────────┐ │
                                    │  │  Live plots + FSM   │ │
                                    │  │  + Fault badge      │ │
                                    │  │  + Modulation viz   │ │
                                    │  └─────────────────────┘ │
                                    │  ┌─────────────────────┐ │
                                    │  │  Command controls   │ │
                                    │  └─────────────────────┘ │
                                    └──────────────────────────┘
```

Built on PySide6 + pyqtgraph + pyserial. The simulator is a pure-Python state-machine mirror of the firmware that requires no hardware — used for fault-condition demos, training, and offline development.

### 11.2 Installation

```powershell
py -3 -m venv dashboard\.venv
dashboard\.venv\Scripts\python -m pip install --upgrade pip
dashboard\.venv\Scripts\python -m pip install -r dashboard\requirements.txt
dashboard\.venv\Scripts\python dashboard\run_dashboard.py
```

### 11.3 Operator Workflow (Bench Session)

1. **Connect first.** Plug the Nucleo's ST-LINK USB before opening the dashboard. Note the assigned COM port (Windows: Device Manager → Ports).
2. **Open dashboard, connect to COM port.** The dashboard sends `STATUS` immediately on connect, cancelling the firmware's 3 s auto-start window.
3. **Flash firmware.** From STM32CubeIDE or `STM32_Programmer_CLI`. The dashboard re-cancels auto-start the moment it sees the post-flash boot message.
4. **Configure VNOM** for the actual bench bus voltage. At low test voltages (e.g. 10 V), set `VNOM 10` to scale protection thresholds appropriately.
5. **Configure modulator.** `MOD PSC` for the 5-level deliverable; `MOD STAIR` for the legacy fallback; `MOD STAIR_ALT` for thermally-balanced staircase without PSC's hardware demands.
6. **Apply DC bus voltage** to both bridges with output limits set conservatively.
7. **START.** Watch the dashboard for `$A,START`, then `$A,RUN` after ~6 ms pre-charge.
8. **Monitor.** Live plots of V_DC1, V_DC2, I_out, the modulation visualization, and the FSM state badge.
9. **STOP.** Cleanly disables MOE and returns to IDLE.

### 11.4 Safety Boundaries

- `START` over live serial is gated behind an "Arm live START" checkbox. The user must explicitly enable the gate before each session.
- Scenario fault buttons (UV, OV, OC, IMBAL, Sensor Lost, etc.) only run against the simulator. They never inject fake sensor values into the firmware. This means a fault-demonstration button cannot accidentally trip a real power stage.
- The dashboard refuses to send `START` over live serial without arming. Other commands (`STATUS`, `STOP`, `MODE`, `CLEAR`, `MI`, etc.) are always available.

---

## 12. Bring-Up & Test

Full bring-up procedures live in the firmware repository:

- **`FIRST_BENCH_SESSION.md`** — recommended first-session walkthrough. Goes from `git pull` to confirmed 5-level PSC output in one continuous procedure, with explicit pass/fail criteria and TLP250 protection checks at every step.
- **`HARDWARE_BRINGUP.md`** — comprehensive phase-by-phase reference. Covers every test phase from continuity to full-voltage PSC sustained run, with troubleshooting trees for every common failure mode.

### 12.1 Condensed Phase Checklist

| Phase | Activity | Pass criterion |
|---|---|---|
| 0 | Firmware sanity (no power) | Boot messages, `$C` config, telemetry @ 20 Hz |
| 1 | Continuity (no power) | No unexpected shorts, all diodes oriented correctly |
| 2 | Gate drive with external 15 V (no DC bus) | Clean Vgs on all 8 MOSFETs, dead-time visible |
| 3 | B0515S supply test | 13–16 V on +15V_Drive under load |
| 4 | Sensing decode (5 V into bus terminal) | `vdc` reads 4.7–5.3 V; SPIINV set correctly |
| 5 | Low-voltage power (10 V bus, STAIR) | 5-level staircase at ±20 V output |
| 6 | Single-bridge isolation | Each bridge in B1/B2 mode produces 3-level output |
| 7 | Full voltage (50 V bus, STAIR) | ±100 V staircase, THD < 5 % |
| 7b | Safe PSC bring-up (5 V, ramping) | 5 levels confirmed at low voltage before raising |
| 8 | PSC at full voltage | 5 distinct levels at ±100 V, bridges thermally balanced |
| 9 | Frequency sweep (optional) | Stable across 1–10 kHz F_sw |
| 10 | Fault injection | All seven fault types trip within 3–4 ms |

### 12.2 Bench-Validated Results (Demo)

At the project demonstration:
- ✅ 5-level PSC output verified on oscilloscope at the cascaded AC output
- ✅ Bridges thermally balanced — Bridge 1 and Bridge 2 MOSFET case temperatures within ~3 °C at sustained 50 V / ~700 W operation
- ✅ `$C,...,lock=OK,cntoff≈3199` reported by firmware (PSC phase-shift confirmed)
- ✅ Full protection system exercised (UV, OV, OC, IMBAL, sensor-lost, manual TRIP)
- ✅ Grounding architecture verified clean (the 5V_GND ↔ 50V_GND issue identified in late iteration was resolved on the populated boards)

---

## 13. V3.1 Errata

The following points in v3.1 are corrected by v4.

### 13.1 Pin-Map Errors (Critical)

**v3.1 listed (incorrect):**
- PWM_1L: PA10 (TIM1_CH2N) → PA10 has *no* TIM1_CH2N alternate function on the STM32F303RE
- PWM_3H/PWM_3L/PWM_4H/PWM_4L on PC6/PC7/PC8/PC9 → only PC6 maps to TIM8_CH1; PC7/PC8/PC9 map to TIM8_CH2/CH3/CH4 respectively, not the complementary outputs

**v4 corrects to:**
- PWM_1L: PA12 (TIM1_CH2N, AF6) ✓
- TIM8 channels: PB6/PB3/PB8/PB0 (CH1/CH1N/CH2/CH2N) ✓ — these are the valid complementary-pair pins for TIM8 on the F303RE package

### 13.2 MOSFET Selection

**v3.1:** IRFZ44N (55 V V_DSS) — insufficient margin against the 1.5KE62A's 84.5 V clamp.
**v4:** IRFB4110 (100 V V_DSS, 4.5 mΩ R_DS(on)) — comfortable margin, lower conduction losses.

### 13.3 Sensing Topology

**v3.1:** Three independent isolated MISO returns, three 6N137 per system.
**v4:** Two isolated MISO returns — DC2 and CUR ADCs wire-share PC3 on the upper-bridge island. Sequential one-CS-at-a-time read in firmware.

### 13.4 Modulation Strategy

**v3.1:** In-Phase Disposition Level-Shifted PWM (IPD LS-PWM) at 5 kHz, no fallback.
**v4:** Three modulators runtime-switchable. PSC-PWM at 5 kHz is the bench-validated deliverable; STAIR (500 Hz quantize) and STAIR_ALT (bridge-balanced quantize) are fallbacks. The active modulator is selectable from the dashboard.

### 13.5 Protection Thresholds

**v3.1:** Fixed thresholds (UV=40 V, OV=58 V, IMBAL=10 V, OC=15 A).
**v4:** Voltage thresholds runtime-configurable via VNOM, scaling all three by fixed ratios. OC remains independent. This enables bench testing at any bus voltage from 5 V to 60 V.

### 13.6 System Clock

**v3.1:** 72 MHz from external 8 MHz crystal (HSE) through PLL.
**v4:** 64 MHz from internal HSI through PLL — no crystal required. All timer arithmetic is derived from the actual clock, so register values differ from v3.1's tables.

### 13.7 Dead-Time

**v3.1:** 500 ns – 1 µs target (sized for IRFZ44N).
**v4:** 3 µs (sized for IRFB4110's ~150 nC gate charge with the same 22 Ω gate resistor).

### 13.8 Maximum Duty Cycle Clamp

**v3.1:** Specified 95 % but indicated 99 % was used.
**v4:** Hard 95 % enforced in firmware, with the OLD 99 % clamp tightened to comply with v3.1 §7.4. Output amplitude impact: ~4 % at MI = 0.95.

### 13.9 Auto-Start

**v3.1:** Not specified.
**v4:** 3-second auto-start fallback if no UART activity received. Standalone deployment supported; dashboard auto-cancels.

### 13.10 Dashboard

**v3.1:** Not present in the design scope.
**v4:** First-class operator interface (PySide6 + pyqtgraph + pyserial) with live plots, simulator-backed scenario playback, and full command coverage.

---

## 14. Safety

Power-stage operation involves voltages and currents capable of causing fire, injury, or fatal electric shock. Observe the following at all times:

- **DC link capacitors store energy for ~8 minutes after power-off.** The 100 kΩ / 2 W bleeders provide passive discharge but verify with a multimeter before touching the bus.
- **The 1.5KE62A TVS will fail short on sustained overvoltage** — protection of last resort, not an operating-point limit.
- **Bridge 2's negative terminal is not at system ground.** Differential probes are required for any measurement spanning the two bridges.
- **Always have an emergency-stop reachable** during operation. The bench supply Output Enable button is sufficient if directly accessible.
- **Heatsinks must be attached to all 8 MOSFETs before applying any DC bus voltage.** No exceptions.
- **Safety glasses** during initial power-up and any voltage ramp. Failed DC link capacitors can vent explosively.
- **No `START` over live serial without explicitly arming the dashboard's safety checkbox.**
- **OPEN mode disables all protection.** Use only for demos with isolated low-voltage supplies.

The firmware enforces:
- Maximum duty cycle 95 %
- Modulation index range 0.0–0.95
- VNOM range 5–60 V
- OC range 0.5–20 A
- Fault latching with operator-acknowledged CLEAR
- MOE driven low in IDLE, BOOT, and FAULT (via `BDTR.OSSI = 1`, all gates forced inactive)

The hardware enforces:
- 15 A blade fuse on each DC input
- 1N5408 reverse-polarity diode
- 1.5KE62A TVS clamp
- 100 kΩ bleeder for capacitor discharge

---

## 15. Future Work

The following items are tracked as roadmap items in the project repository's `roadmap/` directory:

### 15.1 Hardware

- **LC output filter design.** Sized for 5 kHz PSC switching with the 4× ripple-frequency advantage, targeting <2 % output THD into resistive load.
- **Thermal management and enclosure.** Current bench operation uses TO-220 clip-on heatsinks. A purpose-built enclosure with forced-air or aluminum-substrate cooling would enable sustained operation at the 700 W rating.
- **Higher switching frequency exploration.** At F_sw = 10–15 kHz the LC filter shrinks significantly. The IRFB4110 + TLP250 + 22 Ω gate path supports this with no BOM changes; switching losses become the limit. Frequency sweep characterization is the gating test.

### 15.2 Firmware

- **Closed-loop voltage regulation.** Currently MI is set manually. Adding a PI loop on output RMS voltage would compensate for load variations and DC bus droop.
- **Grid-tie phase-lock.** A software PLL on a measured grid voltage would enable grid-following operation. Requires an additional voltage sensor on the AC output.
- **CAN or RS-485 interface.** USART2/VCP is convenient for bench but a galvanically isolated industrial bus is appropriate for any deployed product.

### 15.3 Experimental Tracks (Repository: `experimental/`)

The repository's `experimental/` directory houses untested or research-only work. These tracks are not validated on the project hardware and are gated behind a clear "NOT VALIDATED" banner. They do not appear in the main report but are preserved for future development:

- **RISC-V SoC and hardware PWM accelerator.** A custom RV32IM core with a dedicated zero-jitter PWM peripheral, synthesized to GDSII on the SkyWater 130 nm PDK. Layout complete; no silicon. Provides a future high-performance control path with hardware-enforced dead-time and synchronized carriers.
- **FPGA controller emulation.** Verilog RTL paths for prototyping the RISC-V design on a development FPGA before any silicon commitment.

### 15.4 Product Path

To take this beyond a graduation project requires:
- Safety certification scope (IEC 62109 for inverters, regional variants)
- EMC compliance testing
- Conformal coating and ingress protection
- Production-grade BOM with lifecycle commitment from suppliers
- Manufacturing test fixtures (in-circuit test, programming, calibration)
- A safety case for the closed-loop control firmware

These items are out of scope for the graduation project but are tracked in `roadmap/product-path.md` for future reference.

---

## Appendix A — Quick Reference Card

| Operation | Command |
|---|---|
| Bench test at 12 V bus | `VNOM 12`, then `START` |
| Switch to PSC at full voltage | `MOD PSC`, `FSW 5000`, `VNOM 50`, `START` |
| Single-bridge fault diagnostic | `BRIDGE B1`, `START`, then `BRIDGE B2`, `START` |
| Operator-forced fault demo | `TRIP` from RUN — drops MOE, drives FAULT_OUT low |
| Diagnose dead sensor | `ADCRAW` to see raw counts, then `SPIINV 7` to flip polarity |
| Set conservative current limit | `OC 5` (5 A trip during initial bring-up) |
| Live config snapshot | `CONFIG` emits `$C` and `$P` lines |
| Recover from sensor loss without reboot | `RESCAN` |

## Appendix B — Key Files in the Firmware Repository

| Path | Role |
|---|---|
| `Core/Src/main.c` | System init, clock, GPIO, NVIC, FSM_Init kickoff |
| `Core/Src/pwm_modulator.c` | TIM1+TIM8 setup, STAIR/STAIR_ALT/PSC modulators |
| `Core/Inc/pwm_config.h` | Runtime PWM defaults and bounds |
| `Core/Src/fsm.c` | State machine, command dispatch, auto-start |
| `Core/Src/sensing.c` | 1 kHz sensor scan, IIR filtering, mode logic |
| `Core/Src/spi_mcp3201.c` | Bit-banged SPI driver, SPIINV polarity handling |
| `Core/Src/protection.c` | Threshold checking, debounce, latching |
| `Core/Src/uart_telem.c` | NMEA emit/parse, command tokenizer |
| `dashboard/visual_twin_dashboard/` | PySide6 desktop application |
| `dashboard/visual_twin_dashboard/sim.py` | PC-only simulator mirror of firmware |

---

*End of Build Guide v4.0 — May 2026*

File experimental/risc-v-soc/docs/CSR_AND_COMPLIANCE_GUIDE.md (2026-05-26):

# CSR and Compliance Implementation Guide

**Document Version:** 1.0
**Date:** 2025-12-08
**Stage:** CSR, Interrupts, Exceptions, and Compliance Testing
**Prerequisite:** Completed RV32I + M Extension

---

## Table of Contents

1. [Overview](#overview)
2. [CSR (Control and Status Registers)](#csr-control-and-status-registers)
3. [Privileged Architecture](#privileged-architecture)
4. [Exception Handling](#exception-handling)
5. [Interrupt Handling](#interrupt-handling)
6. [System Instructions](#system-instructions)
7. [Integration with Core](#integration-with-core)
8. [Testing Strategy](#testing-strategy)
9. [RISC-V Compliance Tests](#risc-v-compliance-tests)
10. [Debugging Guide](#debugging-guide)

---

## Overview

### What You'll Implement

This guide covers the final pieces to complete a fully functional RV32IM core:

**Phase 1: CSR Unit (8-10 hours)**
- Control and Status Register file
- CSR read/write/set/clear operations
- Machine-mode CSRs (mstatus, mie, mip, mtvec, mepc, mcause, etc.)

**Phase 2: Exception Handling (6-8 hours)**
- Exception detection (illegal instruction, misaligned access, etc.)
- Trap entry (save PC, update CSRs, jump to handler)
- Trap return (restore state, return from handler)

**Phase 3: Interrupt Handling (8-10 hours)**
- Interrupt controller
- External interrupts
- Timer interrupts
- Software interrupts
- Interrupt priority and masking

**Phase 4: System Instructions (4-6 hours)**
- ECALL (environment call)
- EBREAK (breakpoint)
- MRET (return from machine-mode trap)
- WFI (wait for interrupt)
- CSR instructions (CSRRW, CSRRS, CSRRC, and immediate variants)

**Phase 5: Integration & Testing (10-15 hours)**
- Integrate all components with core
- Write comprehensive testbenches
- Run RISC-V compliance tests
- Debug and fix issues

**Total Estimated Time: 40-50 hours (5-7 weeks @ 8 hours/week)**

### Why CSRs and Interrupts Matter

For your inverter control application, interrupts are **critical**:

```
Timer Interrupt (10 kHz)
        │
        ├─► Read ADC values (current/voltage)
        ├─► Execute control algorithm (PR controller)
        ├─► Update PWM duty cycles
        └─► Clear interrupt flag
```

Without interrupts:
- ❌ Polling is inefficient
- ❌ Timing jitter
- ❌ Missed control deadlines

With interrupts:
- ✅ Deterministic timing
- ✅ Low latency response
- ✅ Efficient CPU usage

---

## CSR (Control and Status Registers)

### What are CSRs?

CSRs are special registers that control processor behavior and store system state. They're separate from the 32 general-purpose registers (x0-x31).

**Key CSRs for RV32IM:**

| CSR Address | Name | Description |
|---|---|---|
| 0x300 | mstatus | Machine status register (interrupt enable, etc.) |
| 0x304 | mie | Machine interrupt enable (which interrupts are enabled) |
| 0x305 | mtvec | Machine trap vector (where to jump on trap) |
| 0x340 | mscratch | Machine scratch register (for trap handlers) |
| 0x341 | mepc | Machine exception PC (return address) |
| 0x342 | mcause | Machine trap cause (which exception/interrupt) |
| 0x343 | mtval | Machine trap value (bad address or instruction) |
| 0x344 | mip | Machine interrupt pending (which interrupts are pending) |

**Performance Counters (Optional but useful):**

| CSR Address | Name | Description |
|---|---|---|
| 0xB00 | mcycle | Machine cycle counter (lower 32 bits) |
| 0xB02 | minstret | Machine instructions retired counter |
| 0xB80 | mcycleh | Machine cycle counter (upper 32 bits) |
| 0xB82 | minstreth | Machine instructions retired (upper 32 bits) |

### CSR Module Implementation

#### Step 1: Create CSR Register File

**File:** `rtl/core/csr_unit.v`

```verilog
/**
 * @file csr_unit.v
 * @brief Control and Status Register Unit for RV32IM
 *
 * Implements machine-mode CSRs for trap handling, interrupts,
 * and performance counters.
 *
 * @author Custom RISC-V Core Team
 * @date 2025-12-08
 * @version 1.0
 */

`include "riscv_defines.vh"

module csr_unit (
    input  wire        clk,
    input  wire        rst_n,

    //==========================================================================
    // CSR Read/Write Interface (from core)
    //==========================================================================

    input  wire [11:0] csr_addr,      // CSR address
    input  wire [31:0] csr_wdata,     // Data to write
    input  wire [2:0]  csr_op,        // Operation: 000=none, 001=RW, 010=RS, 011=RC
    output reg  [31:0] csr_rdata,     // Data read
    output wire        csr_valid,     // CSR address is valid (exists)

    //==========================================================================
    // Trap Interface (from core)
    //==========================================================================

    input  wire        trap_entry,    // Entering trap handler
    input  wire        trap_return,   // Returning from trap (MRET)
    input  wire [31:0] trap_pc,       // PC at time of trap
    input  wire [31:0] trap_cause,    // Exception/interrupt cause
    input  wire [31:0] trap_val,      // Bad address or instruction

    output reg  [31:0] trap_vector,   // Address of trap handler
    output reg  [31:0] epc_out,       // Return address (mepc)

    //==========================================================================
    // Interrupt Interface
    //==========================================================================

    input  wire [31:0] interrupts_i,  // Interrupt lines from peripherals
    output wire        interrupt_pending, // Any interrupt pending
    output wire        interrupt_enabled, // Global interrupt enable
    output reg  [31:0] interrupt_cause,   // Which interrupt to service

    //==========================================================================
    // Performance Counters
    //==========================================================================

    input  wire        instr_retired  // Increment minstret when instruction retires
);

    //==========================================================================
    // CSR Registers
    //==========================================================================

    // Machine Trap Setup
    reg [31:0] mstatus;    // Machine status register
    reg [31:0] mie;        // Machine interrupt enable
    reg [31:0] mtvec;      // Machine trap vector base address

    // Machine Trap Handling
    reg [31:0] mscratch;   // Machine scratch register
    reg [31:0] mepc;       // Machine exception program counter
    reg [31:0] mcause;     // Machine trap cause
    reg [31:0] mtval;      // Machine trap value
    reg [31:0] mip;        // Machine interrupt pending (read-only, reflects interrupts_i)

    // Machine Counters
    reg [63:0] mcycle;     // Cycle counter (64-bit)
    reg [63:0] minstret;   // Instructions retired counter (64-bit)

    // Read-only info registers (hardcoded)
    localparam [31:0] MVENDORID = 32'h00000000;  // Non-commercial implementation
    localparam [31:0] MARCHID   = 32'h00000000;  // Architecture ID (0 = not assigned)
    localparam [31:0] MIMPID    = 32'h00000001;  // Implementation version 1
    localparam [31:0] MHARTID   = 32'h00000000;  // Hardware thread ID 0
    localparam [31:0] MISA      = 32'h40000100;  // RV32I + M extension
                                                  // Bit 30: MXL=01 (32-bit)
                                                  // Bit 8:  I extension
                                                  // Bit 12: M extension

    //==========================================================================
    // mstatus Bit Fields
    //==========================================================================

    // Bit positions (as defined in riscv_defines.vh)
    // `MSTATUS_MIE   = 3   (Machine Interrupt Enable)
    // `MSTATUS_MPIE  = 7   (Previous MIE value)
    // `MSTATUS_MPP_LO/HI = 11,12 (Previous privilege mode - always 11 for M-mode)

    wire mie_bit  = mstatus[`MSTATUS_MIE];
    wire mpie_bit = mstatus[`MSTATUS_MPIE];

    //==========================================================================
    // Interrupt Logic
    //==========================================================================

    // Update mip based on external interrupt lines
    always @(posedge clk or negedge rst_n) begin
        if (!rst_n) begin
            mip <= 32'h0;
        end else begin
            mip <= interrupts_i;
        end
    end

    // Determine if any interrupt is pending and enabled
    wire [31:0] pending_and_enabled = mip & mie;
    assign interrupt_pending = (|pending_and_enabled) && mie_bit;
    assign interrupt_enabled = mie_bit;

    // Priority encoder for interrupts (higher bit = higher priority)
    // Standard RISC-V interrupt priority: external > software > timer
    integer i;
    always @(*) begin
        interrupt_cause = 32'h0;
        for (i = 31; i >= 0; i = i - 1) begin
            if (pending_and_enabled[i]) begin
                interrupt_cause = 32'h80000000 | i;  // Set bit 31 for interrupt
            end
        end
    end

    //==========================================================================
    // Trap Vector Calculation
    //==========================================================================

    // mtvec[1:0] = mode: 00=Direct, 01=Vectored
    // mtvec[31:2] = base address (aligned to 4 bytes)

    wire [1:0]  mtvec_mode = mtvec[1:0];
    wire [31:0] mtvec_base = {mtvec[31:2], 2'b00};

    always @(*) begin
        if (mtvec_mode == 2'b00) begin
            // Direct mode: all traps jump to base address
            trap_vector = mtvec_base;
        end else begin
            // Vectored mode: interrupts jump to base + 4*cause
            if (trap_cause[31]) begin
                // Interrupt: vectored
                trap_vector = mtvec_base + ({trap_cause[30:0], 2'b00});
            end else begin
                // Exception: direct to base
                trap_vector = mtvec_base;
            end
        end
    end

    assign epc_out = mepc;

    //==========================================================================
    // CSR Read Logic
    //==========================================================================

    reg valid;

    always @(*) begin
        csr_rdata = 32'h0;
        valid = 1'b1;

        case (csr_addr)
            // Machine Information Registers
            `CSR_MVENDORID:  csr_rdata = MVENDORID;
            `CSR_MARCHID:    csr_rdata = MARCHID;
            `CSR_MIMPID:     csr_rdata = MIMPID;
            `CSR_MHARTID:    csr_rdata = MHARTID;

            // Machine Trap Setup
            `CSR_MSTATUS:    csr_rdata = mstatus;
            `CSR_MISA:       csr_rdata = MISA;
            `CSR_MIE:        csr_rdata = mie;
            `CSR_MTVEC:      csr_rdata = mtvec;

            // Machine Trap Handling
            `CSR_MSCRATCH:   csr_rdata = mscratch;
            `CSR_MEPC:       csr_rdata = mepc;
            `CSR_MCAUSE:     csr_rdata = mcause;
            `CSR_MTVAL:      csr_rdata = mtval;
            `CSR_MIP:        csr_rdata = mip;

            // Machine Counters
            `CSR_MCYCLE:     csr_rdata = mcycle[31:0];
            `CSR_MCYCLEH:    csr_rdata = mcycle[63:32];
            `CSR_MINSTRET:   csr_rdata = minstret[31:0];
            `CSR_MINSTRETH:  csr_rdata = minstret[63:32];

            // User-accessible counters (shadow mcycle/minstret)
            `CSR_CYCLE:      csr_rdata = mcycle[31:0];
            `CSR_CYCLEH:     csr_rdata = mcycle[63:32];
            `CSR_INSTRET:    csr_rdata = minstret[31:0];
            `CSR_INSTRETH:   csr_rdata = minstret[63:32];

            // Invalid CSR
            default: begin
                csr_rdata = 32'h0;
                valid = 1'b0;
            end
        endcase
    end

    assign csr_valid = valid;

    //==========================================================================
    // CSR Write Logic
    //==========================================================================

    // CSR operations:
    // 000: No operation
    // 001: CSRRW  - Read/Write (write wdata, read old value)
    // 010: CSRRS  - Read and Set bits (set bits from wdata)
    // 011: CSRRC  - Read and Clear bits (clear bits from wdata)
    // 101: CSRRWI - Read/Write Immediate
    // 110: CSRRSI - Read and Set Immediate
    // 111: CSRRCI - Read and Clear Immediate

    wire csr_write = (csr_op != 3'b000);

    reg [31:0] csr_wdata_final;

    always @(*) begin
        case (csr_op[1:0])
            2'b01: csr_wdata_final = csr_wdata;                    // CSRRW/CSRRWI
            2'b10: csr_wdata_final = csr_rdata | csr_wdata;        // CSRRS/CSRRSI
            2'b11: csr_wdata_final = csr_rdata & ~csr_wdata;       // CSRRC/CSRRCI
            default: csr_wdata_final = 32'h0;
        endcase
    end

    always @(posedge clk or negedge rst_n) begin
        if (!rst_n) begin
            // Reset values
            mstatus   <= 32'h0;          // MIE=0 (interrupts disabled)
            mie       <= 32'h0;          // All interrupts disabled
            mtvec     <= 32'h00000000;   // Trap vector at address 0 (should be set by software)
            mscratch  <= 32'h0;
            mepc      <= 32'h0;
            mcause    <= 32'h0;
            mtval     <= 32'h0;
            mcycle    <= 64'h0;
            minstret  <= 64'h0;

        end else begin
            // Update performance counters
            mcycle <= mcycle + 64'd1;
            if (instr_retired) begin
                minstret <= minstret + 64'd1;
            end

            //======================================================================
            // Trap Entry
            //======================================================================

            if (trap_entry) begin
                // Save current state
                mepc   <= trap_pc;        // Save PC
                mcause <= trap_cause;     // Save cause
                mtval  <= trap_val;       // Save trap value (bad address/instruction)

                // Update mstatus
                mstatus[`MSTATUS_MPIE] <= mstatus[`MSTATUS_MIE];  // Save current MIE
                mstatus[`MSTATUS_MIE]  <= 1'b0;                    // Disable interrupts
                mstatus[`MSTATUS_MPP_HI:`MSTATUS_MPP_LO] <= 2'b11; // Previous privilege = M-mode

            //======================================================================
            // Trap Return (MRET)
            //======================================================================

            end else if (trap_return) begin
                // Restore previous state
                mstatus[`MSTATUS_MIE]  <= mstatus[`MSTATUS_MPIE];  // Restore MIE
                mstatus[`MSTATUS_MPIE] <= 1'b1;                     // Set MPIE to 1
                mstatus[`MSTATUS_MPP_HI:`MSTATUS_MPP_LO] <= 2'b11; // Stay in M-mode

            //======================================================================
            // Normal CSR Write
            //======================================================================

            end else if (csr_write && valid) begin
                case (csr_addr)
                    `CSR_MSTATUS:   mstatus   <= csr_wdata_final & 32'h00001888; // Only writable bits
                    `CSR_MIE:       mie       <= csr_wdata_final;
                    `CSR_MTVEC:     mtvec     <= csr_wdata_final;
                    `CSR_MSCRATCH:  mscratch  <= csr_wdata_final;
                    `CSR_MEPC:      mepc      <= csr_wdata_final & 32'hFFFFFFFE; // Clear LSB
                    `CSR_MCAUSE:    mcause    <= csr_wdata_final;
                    `CSR_MTVAL:     mtval     <= csr_wdata_final;

                    // Counters (writable)
                    `CSR_MCYCLE:    mcycle[31:0]   <= csr_wdata_final;
                    `CSR_MCYCLEH:   mcycle[63:32]  <= csr_wdata_final;
                    `CSR_MINSTRET:  minstret[31:0] <= csr_wdata_final;
                    `CSR_MINSTRETH: minstret[63:32]<= csr_wdata_final;

                    // Read-only registers - ignore writes
                    default: ;
                endcase
            end
        end
    end

endmodule
```

#### Step 2: Testing the CSR Unit

**File:** `sim/testbenches/tb_csr_unit.v`

```verilog
`timescale 1ns / 1ps
`include "riscv_defines.vh"

module tb_csr_unit;

    reg        clk;
    reg        rst_n;
    reg [11:0] csr_addr;
    reg [31:0] csr_wdata;
    reg [2:0]  csr_op;
    wire [31:0] csr_rdata;
    wire        csr_valid;

    reg        trap_entry;
    reg        trap_return;
    reg [31:0] trap_pc;
    reg [31:0] trap_cause;
    reg [31:0] trap_val;
    wire [31:0] trap_vector;
    wire [31:0] epc_out;

    reg [31:0] interrupts_i;
    wire       interrupt_pending;
    wire       interrupt_enabled;
    wire [31:0] interrupt_cause;

    reg        instr_retired;

    // Instantiate CSR unit
    csr_unit dut (
        .clk(clk),
        .rst_n(rst_n),
        .csr_addr(csr_addr),
        .csr_wdata(csr_wdata),
        .csr_op(csr_op),
        .csr_rdata(csr_rdata),
        .csr_valid(csr_valid),
        .trap_entry(trap_entry),
        .trap_return(trap_return),
        .trap_pc(trap_pc),
        .trap_cause(trap_cause),
        .trap_val(trap_val),
        .trap_vector(trap_vector),
        .epc_out(epc_out),
        .interrupts_i(interrupts_i),
        .interrupt_pending(interrupt_pending),
        .interrupt_enabled(interrupt_enabled),
        .interrupt_cause(interrupt_cause),
        .instr_retired(instr_retired)
    );

    // Clock generation
    initial clk = 0;
    always #5 clk = ~clk;

    // Test sequence
    initial begin
        $dumpfile("csr_unit.vcd");
        $dumpvars(0, tb_csr_unit);

        // Initialize
        rst_n = 0;
        csr_addr = 12'h0;
        csr_wdata = 32'h0;
        csr_op = 3'b000;
        trap_entry = 0;
        trap_return = 0;
        trap_pc = 32'h0;
        trap_cause = 32'h0;
        trap_val = 32'h0;
        interrupts_i = 32'h0;
        instr_retired = 0;

        #20 rst_n = 1;
        #10;

        $display("=== Test 1: Read-Only Registers ===");
        // Read MISA
        csr_addr = `CSR_MISA;
        #10;
        $display("MISA = 0x%h (expected 0x40000100)", csr_rdata);
        assert(csr_rdata == 32'h40000100) else $error("MISA incorrect!");

        // Read MVENDORID
        csr_addr = `CSR_MVENDORID;
        #10;
        $display("MVENDORID = 0x%h", csr_rdata);

        $display("\n=== Test 2: Write and Read mstatus ===");
        // Write to mstatus using CSRRW
        csr_addr = `CSR_MSTATUS;
        csr_wdata = 32'h00000008;  // Set MIE bit
        csr_op = 3'b001;  // CSRRW
        #10;
        csr_op = 3'b000;  // Stop writing
        #10;
        $display("mstatus after write = 0x%h (expected 0x00000008)", csr_rdata);
        assert(csr_rdata == 32'h00000008) else $error("mstatus write failed!");

        $display("\n=== Test 3: Set bits with CSRRS ===");
        // Set additional bits using CSRRS
        csr_addr = `CSR_MSTATUS;
        csr_wdata = 32'h00000080;  // Set MPIE bit
        csr_op = 3'b010;  // CSRRS
        #10;
        csr_op = 3'b000;
        #10;
        $display("mstatus after CSRRS = 0x%h (expected 0x00000088)", csr_rdata);
        assert(csr_rdata == 32'h00000088) else $error("CSRRS failed!");

        $display("\n=== Test 4: Clear bits with CSRRC ===");
        // Clear bits using CSRRC
        csr_addr = `CSR_MSTATUS;
        csr_wdata = 32'h00000008;  // Clear MIE bit
        csr_op = 3'b011;  // CSRRC
        #10;
        csr_op = 3'b000;
        #10;
        $display("mstatus after CSRRC = 0x%h (expected 0x00000080)", csr_rdata);
        assert(csr_rdata == 32'h00000080) else $error("CSRRC failed!");

        $display("\n=== Test 5: Trap Entry ===");
        // Setup trap vector
        csr_addr = `CSR_MTVEC;
        csr_wdata = 32'h00001000;  // Trap vector at 0x1000
        csr_op = 3'b001;
        #10;
        csr_op = 3'b000;
        #10;

        // Enable interrupts
        csr_addr = `CSR_MSTATUS;
        csr_wdata = 32'h00000008;  // Set MIE
        csr_op = 3'b001;
        #10;
        csr_op = 3'b000;
        #10;

        // Trigger trap
        trap_entry = 1;
        trap_pc = 32'h00000100;
        trap_cause = 32'h8000000B;  // External interrupt
        trap_val = 32'h0;
        #10;
        trap_entry = 0;
        #10;

        // Check mepc
        csr_addr = `CSR_MEPC;
        #10;
        $display("mepc = 0x%h (expected 0x00000100)", csr_rdata);
        assert(csr_rdata == 32'h00000100) else $error("mepc not saved!");

        // Check mcause
        csr_addr = `CSR_MCAUSE;
        #10;
        $display("mcause = 0x%h (expected 0x8000000B)", csr_rdata);
        assert(csr_rdata == 32'h8000000B) else $error("mcause not saved!");

        // Check that interrupts are disabled
        csr_addr = `CSR_MSTATUS;
        #10;
        $display("mstatus = 0x%h (MIE should be 0, MPIE should be 1)", csr_rdata);
        assert(csr_rdata[3] == 1'b0) else $error("MIE not cleared!");
        assert(csr_rdata[7] == 1'b1) else $error("MPIE not set!");

        $display("\n=== Test 6: Trap Return (MRET) ===");
        trap_return = 1;
        #10;
        trap_return = 0;
        #10;

        // Check that interrupts are re-enabled
        csr_addr = `CSR_MSTATUS;
        #10;
        $display("mstatus after MRET = 0x%h (MIE should be 1)", csr_rdata);
        assert(csr_rdata[3] == 1'b1) else $error("MIE not restored!");

        $display("\n=== Test 7: Interrupt Pending ===");
        // Enable timer interrupt in mie
        csr_addr = `CSR_MIE;
        csr_wdata = 32'h00000080;  // Bit 7 = timer interrupt
        csr_op = 3'b001;
        #10;
        csr_op = 3'b000;
        #10;

        // Assert timer interrupt
        interrupts_i = 32'h00000080;
        #20;
        $display("interrupt_pending = %b (expected 1)", interrupt_pending);
        $display("interrupt_cause = 0x%h (expected 0x80000007)", interrupt_cause);
        assert(interrupt_pending == 1'b1) else $error("Interrupt not pending!");
        assert(interrupt_cause == 32'h80000007) else $error("Wrong interrupt cause!");

        $display("\n=== Test 8: Performance Counters ===");
        // Retire some instructions
        repeat (10) begin
            instr_retired = 1;
            #10;
            instr_retired = 0;
            #10;
        end

        // Read minstret
        csr_addr = `CSR_MINSTRET;
        #10;
        $display("minstret = %d (expected 10)", csr_rdata);
        assert(csr_rdata == 32'd10) else $error("minstret incorrect!");

        // Read mcycle
        csr_addr = `CSR_MCYCLE;
        #10;
        $display("mcycle = %d", csr_rdata);

        $display("\n=== All Tests Passed! ===");
        #100 $finish;
    end

endmodule
```

**Run the test:**

```bash
cd sim
iverilog -o tb_csr tb_csr_unit.v ../rtl/core/csr_unit.v
vvp tb_csr
gtkwave csr_unit.vcd
```

**Expected Output:**

```
=== Test 1: Read-Only Registers ===
MISA = 0x40000100 (expected 0x40000100)
MVENDORID = 0x00000000

=== Test 2: Write and Read mstatus ===
mstatus after write = 0x00000008 (expected 0x00000008)

=== Test 3: Set bits with CSRRS ===
mstatus after CSRRS = 0x00000088 (expected 0x00000088)

=== Test 4: Clear bits with CSRRC ===
mstatus after CSRRC = 0x00000080 (expected 0x00000080)

=== Test 5: Trap Entry ===
mepc = 0x00000100 (expected 0x00000100)
mcause = 0x8000000B (expected 0x8000000B)
mstatus = 0x00000088 (MIE should be 0, MPIE should be 1)

=== Test 6: Trap Return (MRET) ===
mstatus after MRET = 0x00000088 (MIE should be 1)

=== Test 7: Interrupt Pending ===
interrupt_pending = 1 (expected 1)
interrupt_cause = 0x80000007 (expected 0x80000007)

=== Test 8: Performance Counters ===
minstret = 10 (expected 10)
mcycle = 305

=== All Tests Passed! ===
```

---

## Privileged Architecture

### Machine Mode Only

For an embedded inverter controller, we only need **Machine mode** (the highest privilege level). This simplifies the design:

- No User mode (no need for privilege level checking)
- No Supervisor mode (no need for virtual memory)
- All code runs at machine level with full access

### Key Concepts

**1. Privilege Levels (we only use M-mode):**
- Machine mode (M): Privilege level 11 (binary)
- Can access all CSRs and memory
- Can execute any instruction

**2. Trap Handling:**
- **Trap** = Exception or Interrupt
- **Exception** = Synchronous event (illegal instruction, misaligned access)
- **Interrupt** = Asynchronous event (timer, external)

**3. Trap Flow:**

```
Normal Execution
      │
      ├─► Exception/Interrupt occurs
      │
      ├─► Save PC → mepc
      │   Save cause → mcause
      │   Save trap value → mtval
      │
      ├─► Disable interrupts (MIE ← 0)
      │   Save old MIE → MPIE
      │
      ├─► Jump to trap vector (mtvec)
      │
      ▼
Trap Handler
      │
      ├─► Save registers (if needed)
      ├─► Handle trap
      ├─► Restore registers
      │
      ├─► Execute MRET
      │
      ├─► Restore MIE ← MPIE
      │   PC ← mepc
      │
      ▼
Resume Normal Execution
```

---

## Exception Handling

### Types of Exceptions

**For RV32IM, you need to detect:**

| Exception Code | Name | When it occurs |
|---|---|---|
| 0 | Instruction address misaligned | PC not 4-byte aligned |
| 1 | Instruction access fault | Instruction fetch error |
| 2 | Illegal instruction | Unknown opcode |
| 3 | Breakpoint | EBREAK instruction |
| 4 | Load address misaligned | Load from unaligned address |
| 5 | Load access fault | Load from invalid address |
| 6 | Store address misaligned | Store to unaligned address |
| 7 | Store access fault | Store to invalid address |
| 11 | Environment call from M-mode | ECALL instruction |

### Exception Detection Module

**File:** `rtl/core/exception_unit.v`

```verilog
`include "riscv_defines.vh"

module exception_unit (
    input  wire [31:0] pc,              // Current PC
    input  wire [31:0] instruction,     // Current instruction
    input  wire [31:0] mem_addr,        // Memory address (for load/store)
    input  wire        mem_read,        // Is load instruction
    input  wire        mem_write,       // Is store instruction
    input  wire        bus_error,       // Bus error from Wishbone
    input  wire        illegal_instr,   // From decoder
    input  wire        ecall,           // ECALL instruction
    input  wire        ebreak,          // EBREAK instruction

    output reg         exception_taken, // Exception occurred
    output reg  [31:0] exception_cause, // Exception code
    output reg  [31:0] exception_val    // Bad address or instruction
);

    always @(*) begin
        exception_taken = 1'b0;
        exception_cause = 32'h0;
        exception_val = 32'h0;

        // Priority encoder (check highest priority first)

        // 1. Instruction address misaligned (PC not 4-byte aligned)
        if (pc[1:0] != 2'b00) begin
            exception_taken = 1'b1;
            exception_cause = `MCAUSE_INSTR_MISALIGN;
            exception_val = pc;

        // 2. Instruction access fault (from bus error on fetch)
        // (Handled in fetch stage - not checked here)

        // 3. Illegal instruction
        end else if (illegal_instr) begin
            exception_taken = 1'b1;
            exception_cause = `MCAUSE_ILLEGAL_INSTR;
            exception_val = instruction;

        // 4. Breakpoint (EBREAK)
        end else if (ebreak) begin
            exception_taken = 1'b1;
            exception_cause = `MCAUSE_BREAKPOINT;
            exception_val = pc;

        // 5. Load address misaligned
        end else if (mem_read) begin
            // Check alignment based on access width
            // (This should be determined by funct3 of the load instruction)
            // For simplicity, we'll check word alignment here
            if (mem_addr[1:0] != 2'b00) begin
                exception_taken = 1'b1;
                exception_cause = `MCAUSE_LOAD_MISALIGN;
                exception_val = mem_addr;
            end else if (bus_error) begin
                // Load access fault
                exception_taken = 1'b1;
                exception_cause = `MCAUSE_LOAD_ACCESS_FAULT;
                exception_val = mem_addr;
            end

        // 6. Store address misaligned / access fault
        end else if (mem_write) begin
            if (mem_addr[1:0] != 2'b00) begin
                exception_taken = 1'b1;
                exception_cause = `MCAUSE_STORE_MISALIGN;
                exception_val = mem_addr;
            end else if (bus_error) begin
                exception_taken = 1'b1;
                exception_cause = `MCAUSE_STORE_ACCESS_FAULT;
                exception_val = mem_addr;
            end

        // 7. Environment call (ECALL)
        end else if (ecall) begin
            exception_taken = 1'b1;
            exception_cause = `MCAUSE_ECALL_M_MODE;
            exception_val = 32'h0;
        end
    end

endmodule
```

---

## Interrupt Handling

### Interrupt Sources

For your inverter controller, you need:

**1. Timer Interrupt (Priority: High)**
- 10 kHz control loop
- Most critical for real-time control

**2. External Interrupts (Priority: Medium-High)**
- ADC conversion complete
- Overcurrent protection
- Fault detection

**3. Software Interrupt (Priority: Low)**
- Rarely used in embedded systems
- Can be used for inter-core communication (not needed here)

### Interrupt Controller Module

**File:** `rtl/core/interrupt_controller.v`

```verilog
`include "riscv_defines.vh"

module interrupt_controller (
    input  wire        clk,
    input  wire        rst_n,

    //==========================================================================
    // External Interrupt Inputs
    //==========================================================================

    input  wire        timer_int,       // Timer interrupt (highest priority)
    input  wire        external_int,    // External interrupt
    input  wire        software_int,    // Software interrupt (lowest priority)
    input  wire [15:0] peripheral_ints, // Additional peripheral interrupts

    //==========================================================================
    // From CSR Unit
    //==========================================================================

    input  wire        global_int_en,   // mstatus.MIE
    input  wire [31:0] mie,             // Which interrupts are enabled

    //==========================================================================
    // To CSR Unit
    //==========================================================================

    output reg  [31:0] interrupt_lines, // Interrupt request lines

    //==========================================================================
    // To Core
    //==========================================================================

    output reg         interrupt_req,   // Interrupt request to core
    output reg  [31:0] interrupt_cause  // Which interrupt (for mcause)
);

    // Standard RISC-V interrupt bit positions:
    // Bit 3:  Machine software interrupt
    // Bit 7:  Machine timer interrupt
    // Bit 11: Machine external interrupt
    // Bits 16-31: Custom/platform-specific

    always @(*) begin
        // Combine all interrupt sources into interrupt_lines
        interrupt_lines = 32'h0;
        interrupt_lines[3]  = software_int;
        interrupt_lines[7]  = timer_int;
        interrupt_lines[11] = external_int;
        interrupt_lines[31:16] = peripheral_ints;
    end

    // Determine which interrupts are both pending and enabled
    wire [31:0] pending_and_enabled = interrupt_lines & mie;

    // Priority encoder: select highest priority interrupt
    always @(*) begin
        interrupt_req = 1'b0;
        interrupt_cause = 32'h0;

        if (global_int_en && (|pending_and_enabled)) begin
            interrupt_req = 1'b1;

            // Priority order (high to low):
            // 1. Machine external interrupt (bit 11)
            // 2. Machine software interrupt (bit 3)
            // 3. Machine timer interrupt (bit 7)
            // 4. Platform-specific (bits 16-31)

            if (pending_and_enabled[11]) begin
                interrupt_cause = `MCAUSE_EXTERNAL_INT;  // 0x8000000B
            end else if (pending_and_enabled[3]) begin
                interrupt_cause = `MCAUSE_SOFTWARE_INT;  // 0x80000003
            end else if (pending_and_enabled[7]) begin
                interrupt_cause = `MCAUSE_TIMER_INT;     // 0x80000007
            end else begin
                // Find first set bit in platform-specific range
                integer i;
                for (i = 31; i >= 16; i = i - 1) begin
                    if (pending_and_enabled[i]) begin
                        interrupt_cause = 32'h80000000 | i;
                    end
                end
            end
        end
    end

endmodule
```

### Interrupt Testing

**File:** `sim/testbenches/tb_interrupt_controller.v`

```verilog
`timescale 1ns / 1ps
`include "riscv_defines.vh"

module tb_interrupt_controller;

    reg        clk;
    reg        rst_n;
    reg        timer_int;
    reg        external_int;
    reg        software_int;
    reg [15:0] peripheral_ints;
    reg        global_int_en;
    reg [31:0] mie;
    wire [31:0] interrupt_lines;
    wire       interrupt_req;
    wire [31:0] interrupt_cause;

    interrupt_controller dut (
        .clk(clk),
        .rst_n(rst_n),
        .timer_int(timer_int),
        .external_int(external_int),
        .software_int(software_int),
        .peripheral_ints(peripheral_ints),
        .global_int_en(global_int_en),
        .mie(mie),
        .interrupt_lines(interrupt_lines),
        .interrupt_req(interrupt_req),
        .interrupt_cause(interrupt_cause)
    );

    initial clk = 0;
    always #5 clk = ~clk;

    initial begin
        $dumpfile("interrupt_controller.vcd");
        $dumpvars(0, tb_interrupt_controller);

        // Initialize
        rst_n = 0;
        timer_int = 0;
        external_int = 0;
        software_int = 0;
        peripheral_ints = 16'h0;
        global_int_en = 0;
        mie = 32'h0;

        #20 rst_n = 1;
        #10;

        $display("=== Test 1: Interrupts Disabled ===");
        timer_int = 1;
        mie = 32'h00000080;  // Enable timer interrupt
        #20;
        $display("interrupt_req = %b (expected 0, global disabled)", interrupt_req);
        assert(interrupt_req == 1'b0) else $error("Interrupt should be disabled!");

        $display("\n=== Test 2: Timer Interrupt ===");
        global_int_en = 1;
        #20;
        $display("interrupt_req = %b (expected 1)", interrupt_req);
        $display("interrupt_cause = 0x%h (expected 0x80000007)", interrupt_cause);
        assert(interrupt_req == 1'b1) else $error("Interrupt not requested!");
        assert(interrupt_cause == `MCAUSE_TIMER_INT) else $error("Wrong cause!");

        $display("\n=== Test 3: Interrupt Priority ===");
        // Assert both timer and external
        external_int = 1;
        mie = 32'h00000880;  // Enable both
        #20;
        $display("interrupt_cause = 0x%h (expected 0x8000000B - external)", interrupt_cause);
        assert(interrupt_cause == `MCAUSE_EXTERNAL_INT) else $error("Priority wrong!");

        $display("\n=== Test 4: Clear Interrupt ===");
        external_int = 0;
        timer_int = 0;
        #20;
        $display("interrupt_req = %b (expected 0)", interrupt_req);
        assert(interrupt_req == 1'b0) else $error("Interrupt not cleared!");

        $display("\n=== All Tests Passed! ===");
        #100 $finish;
    end

endmodule
```

---

## System Instructions

### CSR Instructions

**CSRRW** - CSR Read/Write
```
rd = CSR[csr]
CSR[csr] = rs1
```

**CSRRS** - CSR Read and Set Bits
```
rd = CSR[csr]
CSR[csr] = CSR[csr] | rs1
```

**CSRRC** - CSR Read and Clear Bits
```
rd = CSR[csr]
CSR[csr] = CSR[csr] & ~rs1
```

**Immediate variants:** CSRRWI, CSRRSI, CSRRCI
- Use zero-extended 5-bit immediate instead of rs1

### Privileged Instructions

**ECALL** - Environment Call
```assembly
ecall  # Raise exception (cause = 11 for M-mode)
```
- Used for system calls (though not typical in bare-metal embedded)

**EBREAK** - Breakpoint
```assembly
ebreak  # Raise breakpoint exception (cause = 3)
```
- Used by debuggers

**MRET** - Machine Return
```assembly
mret  # Return from trap handler
```
- PC ← mepc
- mstatus.MIE ← mstatus.MPIE
- mstatus.MPIE ← 1

**WFI** - Wait for Interrupt
```assembly
wfi  # Idle until interrupt
```
- Stalls pipeline until interrupt occurs
- Can be implemented as NOP for simplicity

### Implementation in Decoder

Add to your `decoder.v`:

```verilog
// In decoder.v, add to the OPCODE_SYSTEM case:

`OPCODE_SYSTEM: begin
    case (funct3)
        `FUNCT3_PRIV: begin  // 3'b000
            // Check funct12
            case (instr[31:20])
                `FUNCT12_ECALL: begin
                    // ECALL instruction
                    is_ecall = 1'b1;
                end
                `FUNCT12_EBREAK: begin
                    // EBREAK instruction
                    is_ebreak = 1'b1;
                end
                `FUNCT12_MRET: begin
                    // MRET instruction
                    is_mret = 1'b1;
                end
                `FUNCT12_WFI: begin
                    // WFI instruction
                    is_wfi = 1'b1;
                end
                default: begin
                    illegal_instr = 1'b1;
                end
            endcase
        end

        `FUNCT3_CSRRW, `FUNCT3_CSRRS, `FUNCT3_CSRRC,
        `FUNCT3_CSRRWI, `FUNCT3_CSRRSI, `FUNCT3_CSRRCI: begin
            // CSR instructions
            is_csr = 1'b1;
            csr_op = funct3;
            csr_addr = instr[31:20];

            // For immediate variants, use zimm (zero-extended immediate)
            if (funct3[2]) begin  // Immediate variant
                csr_wdata = {27'b0, instr[19:15]};  // zimm = rs1 field
            end else begin
                // Use rs1 register value
                rs1_addr = instr[19:15];
            end

            rd_addr = instr[11:7];
            reg_write = (rd_addr != 5'b0);  // Write rd if not x0
        end

        default: begin
            illegal_instr = 1'b1;
        end
    endcase
end
```

---

## Integration with Core

### Modify Core State Machine

Your core needs additional states to handle traps:

```verilog
// State machine states
localparam STATE_RESET   = 3'd0;
localparam STATE_FETCH   = 3'd1;
localparam STATE_DECODE  = 3'd2;
localparam STATE_EXECUTE = 3'd3;
localparam STATE_MEM     = 3'd4;
localparam STATE_WB      = 3'd5;
localparam STATE_TRAP    = 3'd6;  // New: handle trap entry
```

### Trap Handling Logic

```verilog
// In your core, add trap handling:

always @(posedge clk or negedge rst_n) begin
    if (!rst_n) begin
        state <= STATE_RESET;
        pc <= RESET_VECTOR;
        // ... other resets
    end else begin
        case (state)
            STATE_RESET: begin
                state <= STATE_FETCH;
            end

            STATE_FETCH: begin
                // Check for interrupts BEFORE fetching
                if (interrupt_req && !stall) begin
                    trap_entry <= 1'b1;
                    trap_pc <= pc;
                    trap_cause <= interrupt_cause;
                    trap_val <= 32'h0;
                    state <= STATE_TRAP;
                end else begin
                    // Normal fetch
                    // ...
                end
            end

            STATE_DECODE: begin
                // ...
            end

            STATE_EXECUTE: begin
                // Check for exceptions
                if (exception_taken) begin
                    trap_entry <= 1'b1;
                    trap_pc <= pc;
                    trap_cause <= exception_cause;
                    trap_val <= exception_val;
                    state <= STATE_TRAP;
                end else if (is_mret) begin
                    // MRET: return from trap
                    trap_return <= 1'b1;
                    pc <= epc_out;
                    state <= STATE_FETCH;
                end else if (is_wfi) begin
                    // WFI: wait for interrupt
                    if (interrupt_pending) begin
                        state <= STATE_FETCH;  // Continue if interrupt pending
                    end
                    // else stay in EXECUTE (stall until interrupt)
                end else begin
                    // Normal execution
                    // ...
                end
            end

            STATE_TRAP: begin
                // Jump to trap handler
                pc <= trap_vector;
                trap_entry <= 1'b0;
                state <= STATE_FETCH;
            end

            // ... other states
        endcase
    end
end
```

### Complete Integration Checklist

- [ ] Instantiate `csr_unit` in core
- [ ] Instantiate `exception_unit` in core
- [ ] Instantiate `interrupt_controller` in core
- [ ] Connect CSR read/write to decoder
- [ ] Add trap entry/return logic to state machine
- [ ] Connect exception detection signals
- [ ] Connect interrupt signals
- [ ] Handle MRET, ECALL, EBREAK in execute stage
- [ ] Update decoder for CSR instructions
- [ ] Add trap state to FSM

---

## Testing Strategy

### Level 1: Unit Tests (Done Above)

✅ CSR unit tested
✅ Interrupt controller tested
✅ Exception unit tested

### Level 2: Integration Tests

**Test Program 1: Simple CSR Access**

```assembly
# test_csr_basic.s
.section .text
.global _start

_start:
    # Write to mscratch
    li x1, 0xDEADBEEF
    csrw mscratch, x1

    # Read back from mscratch
    csrr x2, mscratch

    # Check x2 == 0xDEADBEEF
    li x3, 0xDEADBEEF
    bne x2, x3, fail

    # Set bits in mstatus (enable MIE)
    li x4, 0x00000008
    csrs mstatus, x4

    # Read mstatus
    csrr x5, mstatus

    # Check bit 3 is set
    andi x6, x5, 0x08
    beqz x6, fail

pass:
    li x10, 1  # Success code
    j end

fail:
    li x10, 0  # Failure code

end:
    # Infinite loop
    j end
```

**Test Program 2: Exception Handling**

```assembly
# test_exception.s
.section .text
.global _start

_start:
    # Setup trap vector
    la x1, trap_handler
    csrw mtvec, x1

    # Execute illegal instruction
    .word 0x00000000  # All zeros = illegal

    # Should never reach here
    j fail

trap_handler:
    # Read mcause
    csrr x2, mcause

    # Check mcause == 2 (illegal instruction)
    li x3, 2
    bne x2, x3, fail

    # Read mepc
    csrr x4, mepc

    # Set mepc to skip bad instruction
    addi x4, x4, 4
    csrw mepc, x4

    # Return from trap
    mret

    # After MRET, we continue here
pass:
    li x10, 1
    j end

fail:
    li x10, 0

end:
    j end
```

**Test Program 3: Interrupt Handling**

```assembly
# test_interrupt.s
.section .text
.global _start

_start:
    # Setup trap vector
    la x1, trap_handler
    csrw mtvec, x1

    # Enable machine interrupts in mie (bit 7 = timer)
    li x2, 0x00000080
    csrw mie, x2

    # Enable global interrupts in mstatus (bit 3 = MIE)
    li x3, 0x00000008
    csrw mstatus, x3

    # Wait for interrupt
    li x10, 0  # Counter
wait_loop:
    addi x10, x10, 1
    j wait_loop

trap_handler:
    # Read mcause
    csrr x2, mcause

    # Check if it's an interrupt (bit 31 set)
    srli x3, x2, 31
    beqz x3, fail

    # Check if it's timer interrupt (code 7)
    andi x4, x2, 0x1F
    li x5, 7
    bne x4, x5, fail

    # Clear interrupt (platform-specific)
    # (This would normally write to timer peripheral)

    # Return from trap
    mret

    # After MRET, continue in wait_loop
    # We should see x10 has incremented

fail:
    li x10, 0xFFFFFFFF
    j end

end:
    j end
```

### Level 3: Full System Test

**Complete Test Sequence:**

1. Reset and initialize
2. Write to various CSRs
3. Read back and verify
4. Trigger exceptions (illegal instruction, misaligned access)
5. Verify trap handler called
6. Verify state saved correctly
7. Return from trap
8. Enable interrupts
9. Trigger interrupt
10. Verify interrupt handler called
11. Clear interrupt and return

---

## RISC-V Compliance Tests

### What are Compliance Tests?

Official RISC-V test suite that verifies your core implements the ISA correctly.

- **Location:** https://github.com/riscv/riscv-arch-test
- **Tests:** Pre-written assembly programs with expected outputs
- **Coverage:** All instructions, corner cases, combinations

### Setting Up Compliance Tests

**Step 1: Clone the Test Repository**

```bash
cd /home/furka/5level-inverter/02-embedded/riscv
mkdir -p verification
cd verification
git clone https://github.com/riscv/riscv-arch-test.git
cd riscv-arch-test
```

**Step 2: Build Your Test Harness**

You need to create a "target" that interfaces your core with the tests.

**File:** `verification/riscv_tests/target_custom_core/model_test.h`

```c
#ifndef _COMPLIANCE_MODEL_H
#define _COMPLIANCE_MODEL_H

// Begin test signature (results written here)
#define RVTEST_IO_WRITE_STR(_SP, _STR)

#define RVTEST_IO_INIT
#define RVTEST_IO_ASSERT_GPR_EQ(_SP, _R, _I)
#define RVTEST_IO_ASSERT_SFPR_EQ(_F, _R, _I)
#define RVTEST_IO_ASSERT_DFPR_EQ(_D, _R, _I)

// Define signature area in memory
#define TEST_SIG_START 0x80001000
#define TEST_SIG_END   0x80002000

#endif // _COMPLIANCE_MODEL_H
```

**Step 3: Adapt Tests for Your Core**

You need to:
1. Convert test programs to hex format your simulator understands
2. Run simulation
3. Extract signature (results)
4. Compare with expected outputs

**Script:** `verification/run_compliance.sh`

```bash
#!/bin/bash

# RISC-V Compliance Test Runner for Custom Core

TESTS_DIR="riscv-arch-test/riscv-test-suite/rv32i_m"
WORK_DIR="work"
SIM_DIR="../sim"

mkdir -p $WORK_DIR

echo "=== Running RV32IM Compliance Tests ==="

# List of tests to run
TESTS=(
    "I-ADD-01"
    "I-ADDI-01"
    "I-AND-01"
    "I-ANDI-01"
    "I-AUIPC-01"
    "I-BEQ-01"
    "I-BGE-01"
    # ... add all tests
)

PASSED=0
FAILED=0

for TEST in "${TESTS[@]}"; do
    echo "Running test: $TEST"

    # Compile test
    riscv32-unknown-elf-gcc -march=rv32im -mabi=ilp32 \
        -nostdlib -T linker.ld \
        -o $WORK_DIR/$TEST.elf \
        $TESTS_DIR/$TEST.S

    # Convert to hex
    riscv32-unknown-elf-objcopy -O verilog \
        $WORK_DIR/$TEST.elf \
        $WORK_DIR/$TEST.hex

    # Run simulation
    cd $SIM_DIR
    iverilog -o sim tb_core.v ../rtl/core/*.v
    vvp sim +test=$WORK_DIR/$TEST.hex > $WORK_DIR/$TEST.log
    cd -

    # Extract signature
    grep "SIGNATURE" $WORK_DIR/$TEST.log > $WORK_DIR/$TEST.sig

    # Compare with reference
    if diff $WORK_DIR/$TEST.sig \
            $TESTS_DIR/references/$TEST.reference_output > /dev/null; then
        echo "  ✓ PASSED"
        ((PASSED++))
    else
        echo "  ✗ FAILED"
        ((FAILED++))
    fi
done

echo ""
echo "=== Results ==="
echo "Passed: $PASSED"
echo "Failed: $FAILED"
echo "Total:  $((PASSED + FAILED))"

if [ $FAILED -eq 0 ]; then
    echo "🎉 All tests passed!"
    exit 0
else
    echo "❌ Some tests failed"
    exit 1
fi
```

### Running Compliance Tests

```bash
cd verification
chmod +x run_compliance.sh
./run_compliance.sh
```

**Expected Output:**

```
=== Running RV32IM Compliance Tests ===
Running test: I-ADD-01
  ✓ PASSED
Running test: I-ADDI-01
  ✓ PASSED
Running test: I-AND-01
  ✓ PASSED
...
Running test: M-MUL-01
  ✓ PASSED
Running test: M-DIV-01
  ✓ PASSED

=== Results ===
Passed: 48
Failed: 0
Total:  48
🎉 All tests passed!
```

### Debugging Failed Tests

If tests fail:

1. **Look at the waveform:**
   ```bash
   gtkwave work/I-ADD-01.vcd
   ```

2. **Check the signature:**
   ```bash
   cat work/I-ADD-01.sig
   cat riscv-arch-test/.../references/I-ADD-01.reference_output
   diff work/I-ADD-01.sig references/I-ADD-01.reference_output
   ```

3. **Common issues:**
   - Incorrect ALU operation
   - Wrong immediate encoding
   - Branch target calculation error
   - Load/store alignment issues
   - CSR read/write errors

---

## Debugging Guide

### Common Issues and Solutions

**Issue 1: Interrupts Not Firing**

```
Symptoms: interrupt_req stays 0 even when interrupt asserted
Checks:
  1. mstatus.MIE = 1? (global enable)
  2. mie[bit] = 1? (specific interrupt enabled)
  3. Interrupt actually asserted?
  4. Priority encoder working?
```

**Issue 2: Trap Handler Not Called**

```
Symptoms: Exception occurs but PC doesn't jump to trap_vector
Checks:
  1. trap_entry signal asserted?
  2. mtvec contains valid address?
  3. State machine enters TRAP state?
  4. PC updated correctly?
```

**Issue 3: MRET Doesn't Return Correctly**

```
Symptoms: After MRET, core crashes or jumps to wrong address
Checks:
  1. mepc contains correct return address?
  2. mepc aligned to 4 bytes?
  3. mstatus.MPIE restored to MIE?
  4. PC loaded from mepc?
```

**Issue 4: CSR Instructions Don't Work**

```
Symptoms: CSR values don't change or read wrong
Checks:
  1. Decoder sets is_csr correctly?
  2. CSR address correct?
  3. csr_op correct? (001=RW, 010=RS, 011=RC)
  4. CSR write enable correct?
  5. Check timing (setup/hold)
```

### Debug Features to Add

**1. Debug CSR (Custom)**

```verilog
`define CSR_DEBUG  12'h7FF  // Custom debug CSR

// In csr_unit.v:
reg [31:0] debug_reg;

// Read:
`CSR_DEBUG: csr_rdata = debug_reg;

// Write:
`CSR_DEBUG: debug_reg <= csr_wdata_final;
```

Use this to communicate with testbench.

**2. Assertion Checks**

```verilog
// In your core:
always @(posedge clk) begin
    // Check: PC should always be 4-byte aligned
    assert(pc[1:0] == 2'b00) else begin
        $error("PC misaligned: 0x%h", pc);
        $finish;
    end

    // Check: After MRET, should jump to mepc
    if (trap_return) begin
        assert(pc == epc_out) else begin
            $error("MRET: PC != mepc (PC=0x%h, mepc=0x%h)", pc, epc_out);
        end
    end
end
```

**3. Waveform Markers**

```verilog
// Add markers in simulation for easier debugging
always @(posedge clk) begin
    if (trap_entry) $display(">>> TRAP ENTRY at PC=0x%h, cause=0x%h", pc, trap_cause);
    if (trap_return) $display("<<< TRAP RETURN to PC=0x%h", epc_out);
    if (interrupt_req) $display("!!! INTERRUPT REQUEST: cause=0x%h", interrupt_cause);
end
```

---

## Summary and Next Steps

### What You've Accomplished

By completing this guide, you've implemented:

✅ **CSR Unit**
- Machine-mode CSRs
- Performance counters
- Trap handling CSRs

✅ **Exception Handling**
- All required RV32I exceptions
- Proper state saving/restoration

✅ **Interrupt Handling**
- Timer, external, software interrupts
- Priority encoding
- Interrupt masking

✅ **System Instructions**
- CSR read/write/set/clear
- ECALL, EBREAK, MRET, WFI

✅ **Compliance Testing**
- RISC-V official test suite
- Full ISA verification

### Your Core is Now Complete! 🎉

You have a fully functional **RV32IM core** with:
- 48 instructions (40 RV32I + 8 M extension)
- Exception and interrupt support
- CSR system
- Compliance tested

### Next Steps for Inverter Project

**1. Integrate with SOC**
```
Custom RISC-V Core (done!)
        │
        ├─► Timer Peripheral (generates 10 kHz interrupt)
        ├─► ADC Interface (reads current/voltage)
        ├─► PWM Accelerator (updates duty cycles)
        └─► Protection Unit (overcurrent detection)
```

**2. Port Control Algorithms**
- Convert MATLAB/Simulink models to C
- Compile with RISC-V GCC
- Test on simulation

**3. Deploy to FPGA**
- Synthesize for Artix-7
- Upload to FPGA
- Test with real hardware

**4. Performance Optimization**
- Profile interrupt latency
- Optimize critical paths
- Add custom Zpec instructions if needed

### Milestone Checklist

**Before Moving to Next Stage:**

- [ ] All unit tests passing
- [ ] Integration tests passing
- [ ] Exception handling working (ECALL, EBREAK, illegal instruction)
- [ ] Interrupt handling working (timer, external)
- [ ] MRET correctly returns from traps
- [ ] CSR instructions work (CSRRW, CSRRS, CSRRC)
- [ ] Performance counters incrementing
- [ ] RISC-V compliance tests passing (target: 100%)
- [ ] Waveforms look correct
- [ ] No timing violations
- [ ] Code is documented

**Congratulations on completing your RV32IM core!** 🚀

---

**Document Version:** 1.0
**Last Updated:** 2025-12-08
**Status:** Complete
**Next:** SOC Integration (see `docs/SOC_INTEGRATION_GUIDE.md`)

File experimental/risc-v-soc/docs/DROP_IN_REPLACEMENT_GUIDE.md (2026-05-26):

# Drop-In Replacement Guide: Custom RV32IM Core for VexRiscv SoC

**Document Version:** 1.0
**Date:** 2025-12-03
**Purpose:** Guide for replacing VexRiscv core while preserving all SoC infrastructure

---

## Table of Contents

1. [Executive Summary](#executive-summary)
2. [VexRiscv Interface Analysis](#vexriscv-interface-analysis)
3. [Drop-In Replacement Strategy](#drop-in-replacement-strategy)
4. [Custom Core Wrapper Design](#custom-core-wrapper-design)
5. [Zpec Custom Extension Design](#zpec-custom-extension-design)
6. [Integration Checklist](#integration-checklist)
7. [Simplified Implementation Roadmap](#simplified-implementation-roadmap)
8. [Testing and Verification](#testing-and-verification)

---

## Executive Summary

### The Big Picture

You have a **working VexRiscv SoC** (`riscv-soc-vexrv/`) with:
- ✅ All peripherals working (PWM, sigma-delta ADC, UART, GPIO, protection)
- ✅ Complete firmware drivers
- ✅ Tested in simulation and hardware
- ✅ Build system and toolchain configured

**Goal:** Replace ONLY the VexRiscv core with your custom RV32IM core, keeping everything else.

### Why This Approach?

```
┌─────────────────────────────────────────────────────────┐
│                     VexRiscv SoC                        │
│  ┌────────────────┐                                     │
│  │  VexRiscv Core │  ← REPLACE THIS                    │
│  │  (black box)   │                                     │
│  └────────┬───────┘                                     │
│           │ cmd/rsp protocol                            │
│  ┌────────▼───────┐                                     │
│  │    Wrapper     │  ← KEEP THIS (or adapt slightly)   │
│  │ cmd/rsp → WB   │                                     │
│  └────────┬───────┘                                     │
│           │ Wishbone                                    │
│  ┌────────▼────────────────────────────────────────┐   │
│  │           Wishbone Interconnect                  │   │
│  └────┬─────┬─────┬──────┬──────┬──────┬──────────┘   │
│       │     │     │      │      │      │               │
│    ┌──▼─┐ ┌─▼──┐ ┌▼───┐ ┌▼───┐ ┌▼───┐ ┌▼────┐        │
│    │ROM │ │RAM │ │PWM │ │ADC │ │TIM │ │UART │ ← KEEP │
│    └────┘ └────┘ └────┘ └────┘ └────┘ └─────┘        │
└─────────────────────────────────────────────────────────┘
```

**Key Benefits:**
- 🎯 Reuse **all working peripherals** (PWM, ADC, UART, etc.)
- 🎯 Reuse **all firmware drivers** (no peripheral code changes)
- 🎯 Reuse **memory map** (addresses stay the same)
- 🎯 Reuse **build system** and toolchain
- 🎯 **Only focus on core implementation** + custom instructions

---

## VexRiscv Interface Analysis

### VexRiscv Core Interface

From `vexriscv_wrapper.v` analysis, VexRiscv core has this interface:

```verilog
module VexRiscv (
    input  wire        clk,
    input  wire        reset,  // Active HIGH reset

    // ============ Instruction Bus (iBus) - cmd/rsp protocol ============
    // Command phase: CPU requests instruction
    output wire        iBus_cmd_valid,        // CPU has valid fetch request
    input  wire        iBus_cmd_ready,        // Bus ready to accept command
    output wire [31:0] iBus_cmd_payload_pc,   // Program counter (address)

    // Response phase: Memory provides instruction
    input  wire        iBus_rsp_valid,        // Response is valid
    input  wire        iBus_rsp_payload_error,// Bus error (usually 0)
    input  wire [31:0] iBus_rsp_payload_inst, // Instruction data

    // ============ Data Bus (dBus) - cmd/rsp protocol ============
    // Command phase: CPU requests data read/write
    output wire        dBus_cmd_valid,        // CPU has valid load/store
    input  wire        dBus_cmd_ready,        // Bus ready to accept command
    output wire        dBus_cmd_payload_wr,   // 1=write, 0=read
    output wire [3:0]  dBus_cmd_payload_mask, // Byte enable (4 bits for 32-bit)
    output wire [31:0] dBus_cmd_payload_address, // Memory address
    output wire [31:0] dBus_cmd_payload_data,    // Write data
    output wire [1:0]  dBus_cmd_payload_size,    // Access size (0=byte, 1=half, 2=word)

    // Response phase: Memory provides read data
    input  wire        dBus_rsp_ready,        // Response available
    input  wire        dBus_rsp_error,        // Bus error
    input  wire [31:0] dBus_rsp_data,         // Read data

    // ============ Interrupts ============
    input  wire        timerInterrupt,        // Timer interrupt
    input  wire        externalInterrupt,     // External interrupt
    input  wire        softwareInterrupt      // Software interrupt
);
```

### cmd/rsp Protocol Explained

**Instruction Bus (iBus) - Simplified:**
```
Clock cycle:    1      2      3      4      5
              ┌───┐  ┌───┐  ┌───┐  ┌───┐  ┌───┐
CPU cmd_valid ──┘   └──────────────────────────  (CPU requests instruction)
CPU pc        ──<0x1000>──────────────────────  (PC = 0x1000)
Bus cmd_ready ─────────┘   └───────────────────  (Bus accepts)
Bus rsp_valid ─────────────────┘   └───────────  (Instruction ready)
Bus inst      ─────────────────<0x12345678>────  (Instruction data)

Timeline:
1. CPU: "I want instruction at PC=0x1000" (cmd_valid=1)
2. Bus: "OK, I see your request" (cmd_ready=1)
3. Bus: "Here's your instruction" (rsp_valid=1, inst=0x12345678)
4. CPU: Fetches next instruction
```

**Data Bus (dBus) - Read Example:**
```
Clock cycle:    1      2      3      4
              ┌───┐  ┌───┐  ┌───┐  ┌───┐
CPU cmd_valid ──┘   └─────────────────────
CPU address   ──<0x10000>────────────────  (Read from RAM)
CPU wr        ──────────────────────────── (wr=0, read)
Bus cmd_ready ─────────┘   └──────────────
Bus rsp_ready ─────────────────┘   └──────
Bus data      ─────────────────<0xABCD>───  (Data from memory)
```

**Data Bus (dBus) - Write Example:**
```
Clock cycle:    1      2      3      4
              ┌───┐  ┌───┐  ┌───┐  ┌───┐
CPU cmd_valid ──┘   └─────────────────────
CPU address   ──<0x20100>────────────────  (Write to PWM)
CPU data      ──<0x5678>─────────────────  (Write data)
CPU wr        ────────┘   └───────────────  (wr=1, write)
CPU mask      ──<1111>───────────────────  (All bytes)
Bus cmd_ready ─────────┘   └──────────────
Bus rsp_ready ─────────────────┘   └──────  (Write complete)
```

### Key Observations

1. **Handshaking:** Both command and response use valid/ready handshaking
2. **Separate buses:** Instruction and data are completely independent (Harvard architecture)
3. **Simple protocol:** Much simpler than AXI or full Wishbone
4. **Single-cycle capable:** Can complete in 2-3 clock cycles for fast memory
5. **Error handling:** Both buses have error signals (rarely used)

---

## Drop-In Replacement Strategy

### Three Approaches

#### **Approach 1: Match VexRiscv Interface Exactly (Recommended)**

Create your custom core with the **exact same cmd/rsp interface**:

```verilog
module custom_riscv_core (
    input  wire        clk,
    input  wire        reset,

    // Use IDENTICAL interface as VexRiscv
    output wire        iBus_cmd_valid,
    input  wire        iBus_cmd_ready,
    output wire [31:0] iBus_cmd_payload_pc,
    input  wire        iBus_rsp_valid,
    input  wire [31:0] iBus_rsp_payload_inst,
    // ... (same for dBus)

    // Interrupts
    input  wire        timerInterrupt,
    input  wire        externalInterrupt,
    input  wire        softwareInterrupt
);
    // Your custom RV32IM implementation here
    // + Zpec custom instructions
endmodule
```

**Then in `vexriscv_wrapper.v`, change line 108:**
```verilog
// OLD:
VexRiscv cpu (

// NEW:
custom_riscv_core cpu (
```

**That's it!** Everything else stays the same.

**Pros:**
- ✅ Zero changes to SoC infrastructure
- ✅ All peripherals work immediately
- ✅ Easiest integration
- ✅ Can test incrementally (start with RV32I, add features)

**Cons:**
- ⚠️ Must implement cmd/rsp handshaking in your core
- ⚠️ Slightly more complex core design

---

#### **Approach 2: Native Wishbone Core + Modified Wrapper**

Design your core with **native Wishbone interface**:

```verilog
module custom_riscv_core (
    input  wire        clk,
    input  wire        rst_n,

    // Wishbone instruction bus
    output wire [31:0] iwb_adr_o,
    input  wire [31:0] iwb_dat_i,
    output wire        iwb_cyc_o,
    output wire        iwb_stb_o,
    input  wire        iwb_ack_i,

    // Wishbone data bus
    output wire [31:0] dwb_adr_o,
    output wire [31:0] dwb_dat_o,
    input  wire [31:0] dwb_dat_i,
    output wire        dwb_we_o,
    output wire [3:0]  dwb_sel_o,
    output wire        dwb_cyc_o,
    output wire        dwb_stb_o,
    input  wire        dwb_ack_i,

    // Interrupts
    input  wire [31:0] interrupts
);
    // Your core with native Wishbone
endmodule
```

**Then create `custom_core_wrapper.v`** (replaces `vexriscv_wrapper.v`):
```verilog
module custom_core_wrapper (
    input  wire        clk,
    input  wire        rst_n,

    // Wishbone buses (same as vexriscv_wrapper output)
    output wire [31:0] ibus_addr,
    output wire        ibus_cyc,
    output wire        ibus_stb,
    input  wire        ibus_ack,
    input  wire [31:0] ibus_dat_i,

    output wire [31:0] dbus_addr,
    output wire [31:0] dbus_dat_o,
    input  wire [31:0] dbus_dat_i,
    output wire        dbus_we,
    output wire [3:0]  dbus_sel,
    output wire        dbus_cyc,
    output wire        dbus_stb,
    input  wire        dbus_ack,
    input  wire        dbus_err,

    input  wire [31:0] external_interrupt
);

    // Direct connection - no conversion needed!
    custom_riscv_core cpu (
        .clk(clk),
        .rst_n(rst_n),

        // Instruction bus - direct passthrough
        .iwb_adr_o(ibus_addr),
        .iwb_dat_i(ibus_dat_i),
        .iwb_cyc_o(ibus_cyc),
        .iwb_stb_o(ibus_stb),
        .iwb_ack_i(ibus_ack),

        // Data bus - direct passthrough
        .dwb_adr_o(dbus_addr),
        .dwb_dat_o(dbus_dat_o),
        .dwb_dat_i(dbus_dat_i),
        .dwb_we_o(dbus_we),
        .dwb_sel_o(dbus_sel),
        .dwb_cyc_o(dbus_cyc),
        .dwb_stb_o(dbus_stb),
        .dwb_ack_i(dbus_ack),

        .interrupts(external_interrupt)
    );

endmodule
```

**Then in `soc_top.v`, replace:**
```verilog
// OLD:
vexriscv_wrapper cpu_wrapper (

// NEW:
custom_core_wrapper cpu_wrapper (
```

**Pros:**
- ✅ Simpler core design (standard Wishbone)
- ✅ More reusable (Wishbone is universal)
- ✅ Easier to understand

**Cons:**
- ⚠️ Need to modify one more file (soc_top.v)
- ⚠️ New wrapper file to maintain

---

#### **Approach 3: Hybrid - Internal Wishbone, cmd/rsp Interface**

Design core with **internal Wishbone**, but add **cmd/rsp adapter inside the core module**:

```verilog
module custom_riscv_core (
    // External interface: cmd/rsp (matches VexRiscv)
    output wire        iBus_cmd_valid,
    // ... etc

    // Internal interface: Wishbone
    wire [31:0] internal_iwb_adr;
    wire [31:0] internal_iwb_dat;
    wire        internal_iwb_cyc;
    // ... etc

    // Internal cmd/rsp to Wishbone adapter
    cmd_rsp_to_wb ibus_adapter (
        .cmd_valid(iBus_cmd_valid),
        .cmd_ready(iBus_cmd_ready),
        // ...
        .wb_adr(internal_iwb_adr),
        .wb_dat(internal_iwb_dat),
        // ...
    );

    // Core pipeline uses Wishbone internally
    riscv_pipeline core (
        .iwb_adr_o(internal_iwb_adr),
        // ...
    );
endmodule
```

**Pros:**
- ✅ Best of both worlds
- ✅ Drop-in compatible with VexRiscv
- ✅ Internally uses standard Wishbone

**Cons:**
- ⚠️ More complex core module
- ⚠️ Extra adapter logic (small overhead)

---

### Recommendation

**Use Approach 1 or 2:**

- **Approach 1** if you want zero SoC changes (just swap the core module)
- **Approach 2** if you prefer standard Wishbone (cleaner core design)

For learning purposes, **Approach 1** is recommended because:
- You learn cmd/rsp protocol (simple and elegant)
- Zero changes to existing working SoC
- Can incrementally test

---

## Custom Core Wrapper Design

### Complete Wrapper Template (Approach 1)

Here's a complete wrapper you can use as a starting point:

```verilog
/**
 * @file custom_core_wrapper.v
 * @brief Wrapper for Custom RV32IM Core with cmd/rsp Interface
 *
 * This module wraps the custom RISC-V core to match VexRiscv interface.
 * It's designed to be a DROP-IN replacement for vexriscv_wrapper.v
 *
 * @author Custom RISC-V Core Team
 * @date 2025-12-03
 */

module custom_core_wrapper (
    input  wire        clk,
    input  wire        rst_n,

    // Wishbone Instruction Bus (to memory controller)
    output wire [31:0] ibus_addr,
    output wire        ibus_cyc,
    output wire        ibus_stb,
    input  wire        ibus_ack,
    input  wire [31:0] ibus_dat_i,

    // Wishbone Data Bus (to memory controller)
    output wire [31:0] dbus_addr,
    output wire [31:0] dbus_dat_o,
    input  wire [31:0] dbus_dat_i,
    output wire        dbus_we,
    output wire [3:0]  dbus_sel,
    output wire        dbus_cyc,
    output wire        dbus_stb,
    input  wire        dbus_ack,
    input  wire        dbus_err,

    // Interrupts
    input  wire [31:0] external_interrupt
);

    //==========================================================================
    // Reset Polarity Conversion
    //==========================================================================

    // Custom core uses active-low reset (standard), wrapper provides active-high
    wire reset = !rst_n;

    //==========================================================================
    // Custom Core Native Signals (cmd/rsp protocol)
    //==========================================================================

    // Instruction Bus
    wire        core_ibus_cmd_valid;
    wire        core_ibus_cmd_ready;
    wire [31:0] core_ibus_cmd_payload_pc;
    wire        core_ibus_rsp_valid;
    wire        core_ibus_rsp_payload_error;
    wire [31:0] core_ibus_rsp_payload_inst;

    // Data Bus
    wire        core_dbus_cmd_valid;
    wire        core_dbus_cmd_ready;
    wire        core_dbus_cmd_payload_wr;
    wire [3:0]  core_dbus_cmd_payload_mask;
    wire [31:0] core_dbus_cmd_payload_address;
    wire [31:0] core_dbus_cmd_payload_data;
    wire [1:0]  core_dbus_cmd_payload_size;
    wire        core_dbus_rsp_ready;
    wire        core_dbus_rsp_error;
    wire [31:0] core_dbus_rsp_data;

    //==========================================================================
    // Custom RISC-V Core Instantiation
    //==========================================================================

    custom_riscv_core #(
        .RESET_VECTOR(32'h00000000)  // Start of instruction memory
    ) cpu (
        .clk(clk),
        .reset(reset),

        // Instruction bus (cmd/rsp interface)
        .iBus_cmd_valid(core_ibus_cmd_valid),
        .iBus_cmd_ready(core_ibus_cmd_ready),
        .iBus_cmd_payload_pc(core_ibus_cmd_payload_pc),
        .iBus_rsp_valid(core_ibus_rsp_valid),
        .iBus_rsp_payload_error(core_ibus_rsp_payload_error),
        .iBus_rsp_payload_inst(core_ibus_rsp_payload_inst),

        // Data bus (cmd/rsp interface)
        .dBus_cmd_valid(core_dbus_cmd_valid),
        .dBus_cmd_ready(core_dbus_cmd_ready),
        .dBus_cmd_payload_wr(core_dbus_cmd_payload_wr),
        .dBus_cmd_payload_mask(core_dbus_cmd_payload_mask),
        .dBus_cmd_payload_address(core_dbus_cmd_payload_address),
        .dBus_cmd_payload_data(core_dbus_cmd_payload_data),
        .dBus_cmd_payload_size(core_dbus_cmd_payload_size),
        .dBus_rsp_ready(core_dbus_rsp_ready),
        .dBus_rsp_error(core_dbus_rsp_error),
        .dBus_rsp_data(core_dbus_rsp_data),

        // Interrupts
        .timerInterrupt(1'b0),                    // Use external timer
        .externalInterrupt(|external_interrupt),  // Any bit set
        .softwareInterrupt(1'b0)                  // Not used
    );

    //==========================================================================
    // Instruction Bus: cmd/rsp to Wishbone Adapter
    //==========================================================================

    reg ibus_active;  // Transaction in progress

    always @(posedge clk or posedge reset) begin
        if (reset) begin
            ibus_active <= 1'b0;
        end else begin
            if (core_ibus_cmd_valid && !ibus_active) begin
                // Start new transaction
                ibus_active <= 1'b1;
            end else if (ibus_ack) begin
                // Transaction complete
                ibus_active <= 1'b0;
            end
        end
    end

    // Wishbone outputs
    assign ibus_addr = core_ibus_cmd_payload_pc;
    assign ibus_cyc  = ibus_active;
    assign ibus_stb  = ibus_active;

    // Core inputs
    assign core_ibus_cmd_ready       = !ibus_active;
    assign core_ibus_rsp_valid       = ibus_ack;
    assign core_ibus_rsp_payload_inst = ibus_dat_i;
    assign core_ibus_rsp_payload_error = 1'b0;

    //==========================================================================
    // Data Bus: cmd/rsp to Wishbone Adapter
    //==========================================================================

    reg dbus_active;  // Transaction in progress

    always @(posedge clk or posedge reset) begin
        if (reset) begin
            dbus_active <= 1'b0;
        end else begin
            if (core_dbus_cmd_valid && !dbus_active) begin
                // Start new transaction
                dbus_active <= 1'b1;
            end else if (dbus_ack || dbus_err) begin
                // Transaction complete
                dbus_active <= 1'b0;
            end
        end
    end

    // Wishbone outputs
    assign dbus_addr  = core_dbus_cmd_payload_address;
    assign dbus_dat_o = core_dbus_cmd_payload_data;
    assign dbus_we    = core_dbus_cmd_payload_wr;
    assign dbus_sel   = core_dbus_cmd_payload_mask;
    assign dbus_cyc   = dbus_active;
    assign dbus_stb   = dbus_active;

    // Core inputs
    assign core_dbus_cmd_ready = !dbus_active;
    assign core_dbus_rsp_ready = dbus_ack || dbus_err;
    assign core_dbus_rsp_data  = dbus_dat_i;
    assign core_dbus_rsp_error = dbus_err;

endmodule
```

**Usage:**
1. Save this as `custom_core_wrapper.v` in `rtl/cpu/`
2. Create your `custom_riscv_core.v` with matching interface
3. In `soc_top.v`, replace `vexriscv_wrapper` with `custom_core_wrapper`

---

## Zpec Custom Extension Design

### Overview

The **Zpec** (Power electronics control) extension adds custom instructions optimized for inverter control algorithms.

### Instruction Encoding

RISC-V custom instructions use **custom-0** to **custom-3** opcodes:
```
┌────────┬────────┬────────┬────────┬────────┐
│ custom-0 : 0x0B (0001011) - Reserved for Zpec
│ custom-1 : 0x2B (0101011) - Available
│ custom-2 : 0x5B (1011011) - Available
│ custom-3 : 0x7B (1111011) - Available
└────────┴────────┴────────┴────────┴────────┘
```

**Use custom-0 (0x0B) for Zpec instructions.**

### Zpec Instruction Set

#### 1. **PR Controller Step** (`pr.step`)

**Purpose:** Execute one iteration of Proportional-Resonant controller

**Assembly Syntax:**
```assembly
pr.step rd, rs1, rs2
```

**Encoding (R-type):**
```
31      25 24   20 19   15 14   12 11    7 6      0
┌──────────┬───────┬───────┬───────┬───────┬────────┐
│ 0000000  │  rs2  │  rs1  │  000  │   rd  │ 0001011│
│ funct7   │ src2  │ src1  │funct3 │ dest  │ opcode │
└──────────┴───────┴───────┴───────┴───────┴────────┘
```

**Operation:**
```verilog
// rs1: error value (Q15 fixed-point)
// rs2: address of PR state structure in memory
// rd:  control output (Q15)

typedef struct {
    int16_t kp;           // Proportional gain (Q15)
    int16_t kr;           // Resonant gain (Q15)
    int16_t x_prev;       // Previous input x[n-1]
    int16_t x_prev2;      // Previous input x[n-2]
    int16_t y_prev;       // Previous output y[n-1]
    int16_t y_prev2;      // Previous output y[n-2]
    int16_t b0, b1, b2;   // Resonant numerator coefficients
    int16_t a1, a2;       // Resonant denominator coefficients
} pr_state_t;

// Pseudocode for pr.step:
int16_t error = (int16_t)rs1;
pr_state_t *state = (pr_state_t*)rs2;

// Proportional term: p = kp * error
int32_t p_term = ((int32_t)state->kp * error) >> 15;

// Resonant term (biquad IIR filter):
// y[n] = b0*x[n] + b1*x[n-1] + b2*x[n-2] - a1*y[n-1] - a2*y[n-2]
int32_t r_term = ((int32_t)state->b0 * error) >> 15;
r_term += ((int32_t)state->b1 * state->x_prev) >> 15;
r_term += ((int32_t)state->b2 * state->x_prev2) >> 15;
r_term -= ((int32_t)state->a1 * state->y_prev) >> 15;
r_term -= ((int32_t)state->a2 * state->y_prev2) >> 15;

// Update state
state->x_prev2 = state->x_prev;
state->x_prev = error;
state->y_prev2 = state->y_prev;
state->y_prev = (int16_t)r_term;

// Output: proportional + resonant
rd = (int16_t)(p_term + r_term);
```

**Performance:**
- Standard RV32IM: ~35 instructions, ~350 ns @ 100 MHz
- With `pr.step`: ~1 instruction, ~50 ns @ 100 MHz
- **Speedup: 7×**

**Hardware Implementation:**
```verilog
// In decode stage:
wire is_pr_step = (opcode == 7'b0001011) && (funct3 == 3'b000) && (funct7 == 7'b0000000);

// In execute stage:
if (is_pr_step) begin
    // Read state from memory (rs2 is pointer)
    pr_state <= memory[rs2>>2 +: sizeof(pr_state_t)/4];

    // Compute PR algorithm (use DSP slices for multiply)
    pr_output <= pr_compute(rs1, pr_state);

    // Write back result
    rd_data <= pr_output;

    // Update state in memory
    memory[rs2>>2 +: sizeof(pr_state_t)/4] <= pr_state_updated;
end
```

---

#### 2. **Saturating Add/Subtract** (`qadd`, `qsub`)

**Purpose:** Fixed-point arithmetic with saturation (prevent overflow)

**Assembly Syntax:**
```assembly
qadd rd, rs1, rs2   # Saturating add: rd = saturate(rs1 + rs2)
qsub rd, rs1, rs2   # Saturating subtract: rd = saturate(rs1 - rs2)
```

**Encoding:**
```
qadd: funct7=0000001, funct3=000, opcode=0001011
qsub: funct7=0000001, funct3=001, opcode=0001011
```

**Operation (Q15 format):**
```c
int16_t qadd_q15(int16_t a, int16_t b) {
    int32_t result = (int32_t)a + (int32_t)b;

    // Saturate to Q15 range: -32768 to 32767
    if (result > 32767)
        return 32767;
    else if (result < -32768)
        return -32768;
    else
        return (int16_t)result;
}
```

**Hardware:**
```verilog
wire [31:0] add_result = rs1_data + rs2_data;
wire overflow = (rs1_data[31] == rs2_data[31]) && (add_result[31] != rs1_data[31]);

assign qadd_result = overflow ? (rs1_data[31] ? 32'h8000 : 32'h7FFF)  // Saturate
                               : add_result;                           // Normal
```

---

#### 3. **Dead-Time Compensation** (`dt.comp`)

**Purpose:** Calculate voltage correction for dead-time effects

**Assembly Syntax:**
```assembly
dt.comp rd, rs1, rs2
```

**Encoding:**
```
funct7=0000010, funct3=000, opcode=0001011
```

**Operation:**
```c
// rs1: current direction (bit 0: 1=positive, 0=negative)
// rs2: dead-time in nanoseconds
// rd:  compensation voltage (Q15)

// Dead-time causes voltage error:
// V_error = (dead_time / T_pwm) * V_dc * sign(current)

int16_t dt_comp(uint32_t current_sign, uint32_t dead_time_ns) {
    // Constants (configured by CSR or hardcoded)
    const uint32_t T_PWM_NS = 100000;  // 100 us = 10 kHz
    const int16_t V_DC_Q15 = 16384;    // V_dc in Q15 (e.g., 50V = 0.5 in Q15)

    // Compute: (dead_time / T_pwm) * V_dc
    int32_t error = ((int32_t)dead_time_ns * V_DC_Q15) / T_PWM_NS;

    // Apply sign
    if (current_sign & 1)
        return (int16_t)error;
    else
        return (int16_t)(-error);
}
```

**Hardware:**
```verilog
// Dedicated divider (or use LUT for common dead-times)
wire [15:0] dt_ratio = (dead_time_ns * 32768) / T_PWM_NS;
wire [15:0] compensation = (dt_ratio * V_DC_Q15) >> 15;
assign dt_comp_result = current_sign[0] ? compensation : -compensation;
```

---

#### 4. **Atomic PWM Update** (`pwm.set`)

**Purpose:** Update all 8 PWM channels atomically (no glitches)

**Assembly Syntax:**
```assembly
pwm.set rd, rs1, rs2
```

**Encoding:**
```
funct7=0000011, funct3=000, opcode=0001011
```

**Operation:**
```c
// rs1: pointer to 8×uint16_t duty cycle array
// rs2: enable mask (bit 0-7 for channels 0-7)
// rd:  status (0=success, non-zero=error)

typedef struct {
    uint16_t ch0_duty;  // 0-1000 (0-100.0%)
    uint16_t ch1_duty;
    uint16_t ch2_duty;
    uint16_t ch3_duty;
    uint16_t ch4_duty;
    uint16_t ch5_duty;
    uint16_t ch6_duty;
    uint16_t ch7_duty;
} pwm_array_t;

void pwm_set(pwm_array_t *duties, uint8_t enable_mask) {
    // Write to hardware PWM shadow registers
    PWM_TIM0->CCR1_SHADOW = duties->ch0_duty;
    PWM_TIM0->CCR2_SHADOW = duties->ch1_duty;
    // ... etc for all 8 channels

    // Atomic update: trigger simultaneous transfer
    PWM_CTRL->UPDATE_TRIGGER = 1;  // All channels update on next PWM cycle
}
```

**Hardware:**
```verilog
// In PWM peripheral:
reg [15:0] ccr_shadow [0:7];   // Shadow registers
reg [15:0] ccr_active [0:7];   // Active registers (used by comparator)
reg update_pending;

// When pwm.set executes:
always @(posedge clk) begin
    if (pwm_set_instruction) begin
        // Load shadow registers
        for (i = 0; i < 8; i = i + 1) begin
            if (enable_mask[i])
                ccr_shadow[i] <= duty_array[i];
        end
        update_pending <= 1;
    end

    // On PWM period boundary (counter overflow)
    if (pwm_counter == 0 && update_pending) begin
        // Atomic transfer: shadow → active
        ccr_active <= ccr_shadow;
        update_pending <= 0;
    end
end
```

---

#### 5. **Parallel Fault Check** (`fault.chk`)

**Purpose:** Check multiple fault conditions in parallel

**Assembly Syntax:**
```assembly
fault.chk rd, rs1
```

**Encoding:**
```
funct7=0000100, funct3=000, opcode=0001011
```

**Operation:**
```c
// rs1: pointer to fault threshold structure
// rd:  fault status bitmask (bit 0-31 for different faults)

typedef struct {
    int16_t dc_bus1_max;        // Max DC bus 1 voltage
    int16_t dc_bus2_max;
    int16_t ac_current_max;     // Max AC current magnitude
    int16_t temperature_max;    // Max temperature
    // ... more thresholds
} fault_thresholds_t;

uint32_t fault_chk(fault_thresholds_t *thresholds) {
    uint32_t faults = 0;

    // Read sensors (parallel in hardware)
    int16_t dc_bus1 = ADC->DATA_CH0;
    int16_t dc_bus2 = ADC->DATA_CH1;
    int16_t ac_curr = ADC->DATA_CH2;

    // Parallel comparisons
    if (dc_bus1 > thresholds->dc_bus1_max)     faults |= (1 << 0);
    if (dc_bus2 > thresholds->dc_bus2_max)     faults |= (1 << 1);
    if (abs(ac_curr) > thresholds->ac_current_max) faults |= (1 << 2);
    // ... etc

    return faults;
}
```

**Hardware:**
```verilog
// Parallel comparator tree
wire [31:0] fault_bits;

assign fault_bits[0] = (adc_ch0 > threshold_0);
assign fault_bits[1] = (adc_ch1 > threshold_1);
assign fault_bits[2] = (abs(adc_ch2) > threshold_2);
// ... etc

// Single-cycle result
assign fault_chk_result = fault_bits;

// Optional: Trigger immediate interrupt if any fault
assign fault_interrupt = |fault_bits;
```

---

### Zpec CSR Registers

**Custom CSRs for Zpec configuration:**

```
CSR Address: 0x7C0 - 0x7CF (custom read/write)

0x7C0: ZPEC_CTRL      - Zpec control register
       [0]: ZPEC_ENABLE (1=enable custom instructions)
       [1]: PR_ACCEL_EN (1=enable PR accelerator)
       [2]: DT_COMP_EN  (1=enable dead-time compensation)

0x7C1: PWM_FREQ       - PWM frequency (Hz)
0x7C2: DEAD_TIME      - Dead-time (ns)
0x7C3: V_DC_BUS       - DC bus voltage (Q15)
0x7C4: FAULT_STATUS   - Current fault status (read-only)
0x7C5: FAULT_ENABLE   - Fault enable mask
```

**Usage:**
```assembly
# Enable Zpec
li t0, 0x7
csrw 0x7C0, t0        # Enable all Zpec features

# Configure dead-time
li t1, 1000           # 1000 ns
csrw 0x7C2, t1

# Read fault status
csrr t2, 0x7C4
bnez t2, fault_handler
```

---
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

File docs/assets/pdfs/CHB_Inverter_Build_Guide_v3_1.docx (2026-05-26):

tlp

5-LEVEL CASCADED H-BRIDGE INVERTER

Complete Build, Test & Assembly Guide

Controller-Agnostic Power Stage with Full Isolated Sensing

Version 3.1 — Final

ELE 401/402 Graduation Project

Hacettepe University — Electrical and Electronics Engineering

February 2026

Ahmet • Gökhan • Mücahit • Furkan

# 1. SYSTEM OVERVIEW
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

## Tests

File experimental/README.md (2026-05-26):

# Experimental

> ⚠️ **The tracks in this directory are not validated in hardware.** No silicon was taped out; no FPGA bring-up exists. These are exploratory designs preserved for continuity.
>
> Do not treat anything here as a working subsystem of the inverter. The validated firmware and hardware live in [`../firmware/`](../firmware/) and [`../hardware/`](../hardware/).

## Contents

| Path | Maturity | Notes |
|---|---|---|
| [`risc-v-soc/`](risc-v-soc/) | RTL + GDSII complete; **no silicon** | Custom RV32IM core + integrated peripherals (PWM, ADC, protection, UART, GPIO, memory). Full Cadence Genus → Innovus → GDSII flow against the SkyWater 130 nm PDK. See [`risc-v-soc/README.md`](risc-v-soc/README.md). |
| [`fpga-controller/`](fpga-controller/) | Concept only | Placeholder for a future FPGA-based controller (Zynq or Cyclone). No HDL written. |

## What would be needed to bring these to life

- **RISC-V SoC** — port the RTL to an FPGA first for functional validation, then pick a foundry shuttle (SkyWater open-shuttle, IHP, EuroPractice) for an actual tape-out. Add JTAG, design-for-test, and a level-shifter board to interface the SoC's PWM outputs into the existing TLP250 + 6N137 isolation chain.
- **FPGA controller** — choose a target board, port the modulator from the C firmware to HDL or HLS, and re-do the bring-up on the inverter hardware with the FPGA in place of the STM32.

Neither track is in scope for the graduation report. They are documented here so the work isn't lost, and so a follow-on group can pick up where the team left off.

## Disk economics

The RISC-V SoC track is ≈ 175 MB on disk because of the GDSII files (up to 49 MB for the full SoC layout) and the layout renders. Everything large is tracked through **Git LFS** — see [`../.gitattributes`](../.gitattributes) for the patterns. A fresh clone needs `git lfs install` and `git lfs pull` to retrieve the binaries.

If you only want the inverter and not the experimental tracks, `git clone --filter=blob:none` plus a partial checkout that excludes `experimental/` will save the LFS bandwidth.

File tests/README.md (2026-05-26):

# Tests

Repo-level CI tests. Orthogonal to the dashboard's own unit tests (which live at `firmware/stm32-f303re/dashboard/tests/` after the Phase 2 subtree import).

| Test | Purpose |
|---|---|
| `test_bom_format.py` | Confirms the BOM CSV has the required columns, no blank cells in required fields, and every supplier URL resolves to one of the four approved domains. |
| `test_docs_buildable.py` | Runs `mkdocs build --strict` in a tempdir and fails on any warning. |

Run locally: `py -3.12 -m unittest discover tests`.

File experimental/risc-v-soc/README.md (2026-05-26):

# RISC-V SoC for the 5-Level Inverter (experimental)

> ⚠️ **Not validated in silicon and not in the bring-up path of the inverter.**
> This directory holds a complete RISC-V SoC project — RTL through GDSII — that was developed in parallel with the inverter as an exploratory track. **The graduation deliverable uses the STM32 path.** Nothing in this folder is wired to the as-built hardware.

## What's here

A custom **RV32IM** RISC-V SoC (32-bit integer + multiply-divide), hand-written in Verilog, integrated with the seven peripherals an inverter controller would need (PWM, ADC, protection, timer, GPIO, UART, memory). Taken through a full **Cadence Genus → Innovus → GDSII** flow against the **SkyWater 130 nm** PDK.

```mermaid
flowchart TB
    subgraph SoC[SoC top — rv32im_soc_with_integrated_core]
      Core[Custom RV32IM core<br/>5-state multi-cycle<br/>Wishbone master]
      MDU[MDU<br/>multiply-divide]
      Mem[Memory<br/>32 KB ROM + 64 KB RAM]
      Comm[Communication<br/>UART, GPIO]
      Prot[Protection<br/>OCP / OVP / E-stop / watchdog]
      ADC[ADC subsystem<br/>4-ch sigma-delta, 10 kHz]
      PWM[PWM accelerator<br/>8-ch with dead-time, 10 kHz]
      Bus[Wishbone interconnect]
    end

    Core --> Bus
    MDU --- Core
    Bus --> Mem
    Bus --> Comm
    Bus --> Prot
    Bus --> ADC
    Bus --> PWM
```

The integrated SoC GDSII is at [`macros/soc_integrated/rv32im_soc_with_integrated_core.gds`](macros/soc_integrated/rv32im_soc_with_integrated_core.gds) (≈ 49 MB, LFS-tracked). Per-block GDSII for each subsystem is in the matching `macros/<block>/` subfolder.

## Per-block tape-out summary

| Block | Role | GDSII |
|---|---|---|
| `core_macro` | The RV32IM CPU itself — 5-state multi-cycle pipeline, 32 GP registers, native Wishbone interface | [`macros/core_macro/core_macro.gds`](macros/core_macro/core_macro.gds) |
| `mdu_macro` | Multiply-divide unit — implements M-extension | [`macros/mdu_macro/mdu_macro.gds`](macros/mdu_macro/mdu_macro.gds) |
| `memory_macro` | ROM (32 KB instructions) + RAM (64 KB data); v2 includes the SkyWater SRAM | [`macros/memory_macro/memory_macro.gds`](macros/memory_macro/memory_macro.gds), [`...memory_macro2.gds`](macros/memory_macro/memory_macro2.gds) |
| `protection_macro` | Overcurrent / overvoltage / E-stop / watchdog logic | [`macros/protection_macro/protection_macro.gds`](macros/protection_macro/protection_macro.gds) |
| `adc_subsystem_macro` | 4-channel sigma-delta ADC subsystem at 10 kHz | [`macros/adc_subsystem_macro/adc_subsystem_macro.gds`](macros/adc_subsystem_macro/adc_subsystem_macro.gds) |
| `pwm_accelerator_macro` | 8-channel PWM generator with hardware dead-time insertion | [`macros/pwm_accelerator_macro/pwm_accelerator_macro.gds`](macros/pwm_accelerator_macro/pwm_accelerator_macro.gds) |
| `communication_macro` | UART (115200 baud, 8N1) + 32-pin GPIO | [`macros/communication_macro/communication_macro.gds`](macros/communication_macro/communication_macro.gds) |
| `rv32im_integrated` | Core + MDU + register file integrated (no peripherals) | [`macros/rv32im_integrated/rv32im_integrated_macro.gds`](macros/rv32im_integrated/rv32im_integrated_macro.gds) |
| `soc_integrated` | **Full SoC** — RV32IM + all peripherals + memory | [`macros/soc_integrated/rv32im_soc_with_integrated_core.gds`](macros/soc_integrated/rv32im_soc_with_integrated_core.gds) |

Each macro also ships a `.lef` (cell placement), `.sdc` (timing constraints), `*_netlist.v` (post-PnR netlist), and `*_stub.v` (interface stub for higher-level synthesis).

## Layout renders

The [`renders/`](renders/) directory holds PNG layouts for every block in two variants:

| Variant | Purpose | Files |
|---|---|---|
| [`renders/blueprint/`](renders/blueprint/) | Bluish PCB-blueprint style — good for posters and presentation | 11 files |
| [`renders/clean/`](renders/clean/) | High-contrast clean render — good for embedding in documentation | 11 files |

Headline: the full-SoC clean render is at [`renders/clean/rv32im_integrated_macro.png`](renders/clean/rv32im_integrated_macro.png).

## What's *not* here

This experimental track is intentionally **not** wired into the inverter's bring-up:

- No silicon tape-out. The GDSII files exist; no foundry submission was made.
- No FPGA equivalence check. The RTL could be ported to a Zynq / Cyclone for in-system validation; that work isn't done.
- No level-shifter board to interface the SoC's PWM outputs to the existing TLP250 + 6N137 isolation chain.
- No JTAG debug interface in the current design.

If someone picks this up, [`docs/IMPLEMENTATION_ROADMAP.md`](docs/IMPLEMENTATION_ROADMAP.md) and [`docs/HANDMADE_README.md`](docs/HANDMADE_README.md) (the project's own README, preserved verbatim from the source tree) are the starting points.

## Directory layout

```
experimental/risc-v-soc/
├── README.md                 # This file
├── rtl/                      # Verilog source — core, peripherals, memory, bus, soc
├── firmware/                 # Embedded C drivers + example programs
├── sim/                      # Verilog testbenches + open-source simulation harness
├── synthesis/                # Synthesis scripts (Cadence Genus + open-source Yosys)
├── programs/                 # Example RISC-V programs that run on the SoC
├── tools/                    # Build / lint helpers
├── constraints/              # FPGA constraint files (Basys3 example)
├── docs/                     # Architecture + implementation docs (12 files)
│   ├── CSR_*.md              # Control / status register architecture
│   ├── MDU_*.md              # Multiply-divide unit
│   ├── ZPEC_*.md             # Custom power-electronics extensions
│   ├── IMPLEMENTATION_ROADMAP.md
│   └── HANDMADE_README.md    # Original project README
├── macros/                   # Per-block tape-out artifacts (GDS / LEF / SDC / netlist)
│   ├── adc_subsystem_macro/
│   ├── communication_macro/
│   ├── core_macro/
│   ├── mdu_macro/
│   ├── memory_macro/
│   ├── protection_macro/
│   ├── pwm_accelerator_macro/
│   ├── rv32im_integrated/
│   └── soc_integrated/       # The full SoC
└── renders/
    ├── blueprint/            # Poster-style layouts (11 PNGs)
    └── clean/                # Documentation-style layouts (11 PNGs)
```

## How to open the GDSII

The GDSII files are LFS-tracked. After cloning the repo, you'll need Git LFS installed and the files pulled:

```powershell
git lfs install
git lfs pull
```

Then open in any GDSII viewer — **KLayout** is the standard free choice. The full SoC layout:

```powershell
klayout experimental/risc-v-soc/macros/soc_integrated/rv32im_soc_with_integrated_core.gds
```

## License + PDK notes

The RTL is licensed under Apache-2.0 along with the rest of this repository. The GDSII files were produced against the [SkyWater 130 nm PDK](https://github.com/google/skywater-pdk), which has its own open-source license (Apache-2.0). No part of the SkyWater PDK is included in this repository — only the project's own GDSII output, which references PDK cells by name.

## Why this is documented but not linked from the main report

Per the project's editorial decision: the graduation deliverable is the **STM32-based 5-level inverter**. The RISC-V SoC is preserved for continuity (someone may pick it up; the work is real and substantial) but is intentionally outside the main report's scope. The main repo [`README.md`](../../README.md) and this folder are the only places the experimental track is linked from.

If you're reading this looking to extend the inverter project: start at [`../../README.md`](../../README.md) and look at the [Future / Experimental tracks](../README.md) section. The RISC-V silicon path is one possible future; an FPGA controller ([`../fpga-controller/`](../fpga-controller/)) is another.

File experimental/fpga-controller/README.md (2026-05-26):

# Experimental — FPGA controller

> ⚠️ **Concept only.** Nothing has been written, simulated, or wired.

A placeholder for a future controller that would replace the STM32 with an FPGA — likely Zynq-7000 or Cyclone V — to:

- Move the modulator into hardware for sub-microsecond determinism.
- Add space for closed-loop control with on-fabric ADC interfacing.
- Provide a path to integrating the [RISC-V SoC](../risc-v-soc/) RTL as a soft core for the dashboard/UART side, with the hard FPGA handling the modulation.

When someone takes this on, populate this directory with the HDL sources, the constraints file, and the bring-up plan. Until then it is intentionally empty.

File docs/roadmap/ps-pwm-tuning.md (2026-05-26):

---
title: PSC-PWM tuning
---

# PSC-PWM tuning

PSC-PWM is the as-built default modulator (see [modulators](../firmware/modulators.md)) and was bench-validated at 5 kHz with both bridges thermally matched. This roadmap item covers **further tuning** beyond what was demonstrated.

## What's already in place

| | Status |
|---|---|
| 90° carrier phase shift between TIM8 and TIM1 | Working — `lock=OK` reported consistently |
| Carrier-phase lock diagnostic (`g_pwm_measured_cnt_offset` + `g_pwm_phase_locked`) | Published on every `$C,...,cntoff=N,lock=OK\|BAD` config line |
| Runtime switching-frequency sweep via `FSW` UART command | 100 Hz – 20 kHz allowed |
| Hard fallback to `STAIR_ALT` if PSC `lock=BAD` | Operator-selectable from dashboard |
| Bench validation at 5 kHz | Five distinct cascade levels at 100 V, bridges thermally matched within ≈ 3 °C |

## What this item covers

### Switching-frequency sweep

A structured sweep across the firmware's allowed `FSW` range (100 Hz to 20 kHz) to characterise the tradeoffs:

| f<sub>sw</sub> | What changes |
|---:|---|
| Lower (≤ 1 kHz) | Lower switching loss; lower thermal load; output ripple becomes audible / larger; LC filter needs to be bigger |
| Headline 5 kHz | Bench-validated; balance of loss + filter size |
| Higher (≥ 10 kHz) | Switching loss climbs (dead time becomes a larger fraction of period); ripple energy moves up where smaller LC filters work; gate-loop parasitics become more important to control |

Deliverables: per-frequency measurement of cascade-output THD (pre-filter), bridge case-temperature delta, gate-loop ringing on the scope. A 5-point sweep (500 Hz, 1 kHz, 5 kHz, 10 kHz, 20 kHz) of 5 minutes per point would be a one-session experiment. Telemetry replay from each run is in the dashboard's replay format.

### Carrier-phase offset sweep

The PSC carrier phase shift is currently fixed at 90° (TIM8 CNT preset to `ARR/2`). For 2 cells this is textbook-optimal — phase shift = 360°/N = 180° for 2 cells, but unipolar modulation uses half that = 90°. The roadmap question: does fine-tuning the phase by a few degrees give measurable improvement under partial bridge mismatch (e.g. different supply rails, different MOSFET binning)?

Implementation hint: add a runtime `PHASE <offset_ticks>` UART command that adjusts the TIM8 CNT preset away from `ARR/2`. The lock-detection logic then checks `cntoff` against the new target, not against ARR/2. Tunable by sweep, measurable by FFT.

### Closed-loop carrier lock

Today, if `lock=BAD` is reported, the operator manually falls back to `STAIR_ALT`. A closed-loop variant would have the firmware:

1. Detect `lock=BAD` after every config change.
2. Auto-retry the phase-shift application up to N times.
3. If still bad, auto-select `STAIR_ALT` and emit a UART notification.

Implementation hint: a few additional state transitions in [`fsm.c`](https://github.com/feaksel/chb-inverter/blob/main/firmware/stm32-f303re/Core/Src/fsm.c) plus a counter. No hardware change.

## Effort estimate

| Sub-item | Engineer-time |
|---|---|
| Switching-frequency sweep + write-up | 1 day bench + 1 day analysis |
| Phase-offset sweep | 1 day bench + 1 day analysis (requires the runtime PHASE command) |
| Closed-loop carrier lock | 2 days firmware + bench verification |

## Why this matters

The carrier-shift `lock=OK\|BAD` diagnostic was added defensively before the first bench session — it caught a real issue immediately ([iteration-4](../iteration-history/iteration-4.md)). Extending it to auto-recovery and adding structured sweep data is the next step in making PSC robust enough to ship in any product version of this design.

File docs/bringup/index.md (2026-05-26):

# Bring-up

<figure markdown="span">
  Lab power sources during bench test
  <figcaption>Bench power supplies on a bring-up session — two independent isolated DC sources, one per bridge, plus a separate 15 V for the gate drive.</figcaption>
</figure>

Two documents cover putting the populated boards on the bench:

| Page | When to use it |
|---|---|
| [First bench session](first-session.md) | The first time you bring the new branch up. Linear procedure with explicit pass/fail checkpoints; covers Step 0, Phases 2–7b, Phase 8 of the reference, plus TLP250-protection checks at every step. **Start here.** |
| [Bring-up reference](reference.md) | Comprehensive phase-by-phase reference with what-the-firmware-does, scope captures, UART output, and troubleshooting trees. Consult when the first-session doc doesn't match what you're seeing. |

The procedural reference is also in [Build Guide v4.0 — §12 Bring-up procedure](../hardware/build-guide-v4.md). Where the first-session notes contradict the guide, **the session notes win** — they describe what was actually seen, not what was expected.

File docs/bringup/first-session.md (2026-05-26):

# First bench session

The linear, single-session walkthrough for putting the populated boards on the bench for the first time and getting all three modulators (STAIR, STAIR_ALT, PSC) verified end-to-end.

This page renders [`firmware/stm32-f303re/FIRST_BENCH_SESSION.md`](https://github.com/feaksel/chb-inverter/blob/main/firmware/stm32-f303re/FIRST_BENCH_SESSION.md) verbatim — the file ships in the firmware repository and is the authoritative copy.

> **Headline safety goal:** do not burn a TLP250, do not burn a MOSFET. Every step has explicit pass/fail criteria; **if anything is unexpected, STOP** and consult the [bring-up reference](reference.md) troubleshooting before continuing.

---

{%
  include-markdown "../../firmware/stm32-f303re/FIRST_BENCH_SESSION.md"
  heading-offset=1
  start="## What to have ready at the bench"
%}

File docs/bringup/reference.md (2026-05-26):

# Hardware bring-up reference

The comprehensive phase-by-phase bring-up reference. Companion to Build Guide v4.0 §12 — the guide covers what to *do* on the hardware; this document covers what the **firmware** does at each step, what to expect on UART, what scope captures should look like, and the troubleshooting trees.

This page renders [`firmware/stm32-f303re/HARDWARE_BRINGUP.md`](https://github.com/feaksel/chb-inverter/blob/main/firmware/stm32-f303re/HARDWARE_BRINGUP.md) verbatim — the file ships in the firmware repository and is the authoritative copy.

> **Read this top to bottom. Do not skip phases.** Each phase builds confidence for the next. Skipping risks damaging components that took weeks to source.
>
> For a faster, focused single-session walkthrough, use the [first bench session](first-session.md) page instead. Come back here when something doesn't match the first-session doc.

---

{%
  include-markdown "../../firmware/stm32-f303re/HARDWARE_BRINGUP.md"
  heading-offset=1
  start="## Step 0 — Getting the firmware onto the board"
%}

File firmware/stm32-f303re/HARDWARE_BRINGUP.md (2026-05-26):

# Hardware Bringup — 5-Level CHB Inverter

Companion to the team's `CHB_Inverter_Build_Guide_v3_1.pdf` section 6
("Test Procedures"). The guide covers what to *do* on the hardware; this
document covers what the **firmware** does at each step, the UART
commands to send, the telemetry/scope outputs to expect, and what to do
when something is off.

**Read this from top to bottom. Do not skip phases.** Each phase builds
confidence for the next. Skipping risks damaging components that took
weeks to source.

> 📘 **Looking for a faster, focused walkthrough?**
> [FIRST_BENCH_SESSION.md](FIRST_BENCH_SESSION.md) is a linear single-session
> procedure that folds together the relevant bits of this doc (Step 0,
> Phases 2–7b, Phase 8) and adds explicit TLP250-protection checks.
> Use it the first time you bench-test the new branch. Come back here
> for the comprehensive reference and troubleshooting trees.

---

## Step 0 — Getting the firmware onto the board

This is the end-to-end procedure from "the code lives in the
`pwm-rewrite-configurable` branch on the dev PC" to "the firmware is
running on the Nucleo and the dashboard is showing telemetry."

If everything is already on the bench PC and flashed, skip to
[Pre-bringup checklist](#pre-bringup-checklist).

### 0.A — Commit the branch (on the dev PC, if not yet committed)

Check current state:
```powershell
cd C:\Users\furka\Projects\5-Level-Cascaded-H-bridge-Inverter-with-STM32-Nucleo-F303RE
git status
git branch --show-current     # must print: pwm-rewrite-configurable
```

If `git status` shows modified or untracked files, commit them:
```powershell
git add -A
git commit -m "PSC-PWM rewrite: configurable modulator, runtime config, auto-start, STAIR_ALT"
```

Push to remote so the bench PC can pull:
```powershell
git push -u origin pwm-rewrite-configurable
```

After the first push, confirm the branch is visible on GitHub
(or whatever remote you use).

### 0.B — Clone (or pull) onto the bench PC

**Fresh bench PC, empty folder, no git history yet:**
```powershell
# Make a Projects folder if you don't have one yet
mkdir C:\Projects -ErrorAction SilentlyContinue
cd C:\Projects

# Clone your fork (the one we pushed to in 0.A)
git clone https://github.com/feaksel/5-Level-Cascaded-H-bridge-Inverter-with-STM32-Nucleo-F303RE.git
cd 5-Level-Cascaded-H-bridge-Inverter-with-STM32-Nucleo-F303RE

# Default branch on clone is main; switch to the working branch
git checkout pwm-rewrite-configurable
```

GitHub will prompt for credentials on the first clone — use a Personal
Access Token (Settings → Developer settings → Personal access tokens →
Tokens (classic) → Generate new, scope `repo`). Paste the token as the
password; Windows Credential Manager remembers it after that.

If git isn't installed: get it from
[git-scm.com/download/win](https://git-scm.com/download/win),
accept defaults, restart PowerShell.

**Bench PC already has the repo from a previous session:**
```powershell
cd C:\Projects\5-Level-Cascaded-H-bridge-Inverter-with-STM32-Nucleo-F303RE
git fetch
git checkout pwm-rewrite-configurable
git pull
```

**Verify you got the right branch and the latest code:**
```powershell
git log --oneline -3
git branch --show-current     # must print: pwm-rewrite-configurable
```

The newest commit message should match what you pushed in 0.A.

### 0.C — Build in STM32CubeIDE

> 💡 **Recommended ordering of the remaining sub-steps:** 0.C build →
> 0.E install/launch dashboard and connect to COM port → 0.D flash. The
> reason is the auto-start race explained at the top of 0.D — having the
> dashboard already connected before the flash completes guarantees
> auto-start gets cancelled on the post-flash reset.

1. Launch **STM32CubeIDE**.
2. Pick a workspace folder when prompted (any empty folder — the workspace
   is just project metadata, not the source).
3. **File → Open Projects from File System...**
4. Click **Directory...** and browse to the cloned repo root (the folder
   containing `.project` and `5levelchb.ioc`).
5. Click **Finish**. CubeIDE imports the project and starts indexing.
6. Wait for indexing to finish (~30-60 s — watch progress bar bottom
   right; it says things like *"C/C++ Indexer"*).
7. **Project → Build All** (or `Ctrl+B`, or click the hammer icon in
   the toolbar).
8. When the build finishes the Console panel at the bottom should show:
   ```
   arm-none-eabi-size  Debug/5levelchb.elf
      text    data     bss     dec     hex filename
     36660     468    3668   40796    9f5c Debug/5levelchb.elf

   Finished building target: 5levelchb.elf
   ```
9. Build artifacts land in `Debug/`:
   - `5levelchb.elf` — for CubeIDE flashing / debugging
   - `5levelchb.bin` — for drag-and-drop flashing
   - `5levelchb.hex` — for STM32CubeProgrammer
   - `5levelchb.map` — link map

Build errors? Read the first error in the Console panel and fix.
Common ones:
- *"Cannot resolve include ... arm-none-eabi-gcc"* — CubeIDE toolchain
  not installed. **Help → Check for Updates** and install missing pieces.
- *"undefined reference to ..."* — a `.c` file isn't being picked up.
  Right-click the file in Project Explorer → **Resource Configurations
  → Reset to Default**.

### 0.D — Flash the Nucleo

> ⚠️ **Critical ordering: open the dashboard and connect to the COM port
> BEFORE you flash.** The firmware auto-starts 3 seconds after every
> reset (including the reset CubeIDE issues at the end of programming).
> If the dashboard isn't connected and listening, you'll race the
> auto-start countdown. The dashboard auto-cancels by sending `STATUS`
> the moment it sees the boot message in the RX stream, so as long as
> it's already connected when the flash completes, you're safe.
>
> The ST-LINK exposes two independent USB endpoints — SWD (used by
> CubeIDE for programming) and VCP (used by the dashboard for UART) —
> so the two can run simultaneously without conflict.
>
> For Phase 0–1 (no power stages connected) auto-start firing is
> harmless — the MOSFET gates are unwired. From Phase 2 onward (gate
> drivers powered) this matters. **Make "dashboard first, then flash"
> a habit from the very first flash so you don't forget later.**

Pick **one** of these three methods. CubeIDE method is easiest if you
already have it open.

**Method 1 — CubeIDE Run/Debug button (recommended on first flash):**
1. Plug the Nucleo-F303RE into the PC via USB (the larger USB connector
   on the ST-LINK side, not the user USB).
2. Wait ~10 s for ST-LINK enumeration. The red LED on the ST-LINK side
   stops blinking and turns solid (or off, depending on board rev).
3. In CubeIDE: **Run → Run As → STM32 C/C++ Application**, or click the
   green play arrow in the toolbar.
4. First run only: CubeIDE pops up a "Debug Configurations" dialog.
   Accept defaults, click **OK**.
5. CubeIDE flashes the device. Status bar shows:
   ```
   Erasing flash... Programming... Verifying... Programming complete.
   ```
6. Nucleo resets and starts running the new firmware.

**Method 2 — Drag and drop (no CubeIDE needed after build):**
1. Plug Nucleo in via USB.
2. A removable drive named **NODE_F303RE** appears in File Explorer
   (one of the ST-LINK USB drives).
3. Open Explorer, drag `Debug\5levelchb.bin` onto the `NODE_F303RE`
   drive.
4. The drive's LED flickers, drive disconnects briefly (~3-5 s), then
   reappears. Flash complete.
5. Nucleo auto-resets and starts running.

**Method 3 — STM32CubeProgrammer CLI:**
```powershell
& "C:\Program Files\STMicroelectronics\STM32Cube\STM32CubeProgrammer\bin\STM32_Programmer_CLI.exe" `
    -c port=SWD `
    -w Debug\5levelchb.hex `
    -rst
```

### 0.E — Set up the dashboard

First-time setup (skip if `dashboard\.venv` already exists):
```powershell
cd C:\Users\furka\Projects\5-Level-Cascaded-H-bridge-Inverter-with-STM32-Nucleo-F303RE
py -3 -m venv dashboard\.venv
dashboard\.venv\Scripts\python -m pip install --upgrade pip
dashboard\.venv\Scripts\python -m pip install -r dashboard\requirements.txt
```

Every time after that:
```powershell
dashboard\.venv\Scripts\python dashboard\run_dashboard.py
```

In the dashboard window:
1. **Source** dropdown (top-left) → select **"Live serial"**.
2. Click **Refresh** next to the COM dropdown — your ST-LINK VCP port
   appears (typically `COMx` where x is some number; check Windows
   Device Manager → Ports if unsure).
3. Select that port, click **Connect**.
4. Status label changes to **"Connected to COMx"**.

If the COM dropdown shows "No ports": the ST-LINK USB driver isn't
installed. Download **ST-LINK USB driver** from [st.com](https://www.st.com/)
and reboot.

### 0.F — First boot verification (no power stages)

1. **Verify auto-start is cancelled by the dashboard.** The dashboard
   does two things to permanently prevent auto-start while connected:
   - On serial connect → sends `STATUS`, flipping
     `UART_ActivitySeen()` on the MCU.
   - On every detected `$A,BOOT_SELF_TEST_DONE` (i.e. every Nucleo
     reset while the dashboard is connected) → re-sends `STATUS`, so
     the flag is set again before the fresh 3 s window expires.

   Look for `[TX] STATUS (auto-cancel)` after the SERIAL connect
   message, and `[TX] STATUS (auto-cancel post-reset)` after each
   reset. With the dashboard connected you have full manual control
   and the inverter will NOT start on its own.

2. Press the Nucleo's **black reset button**.
3. Watch the Raw UART event log on the dashboard. Within ~1 second of
   reset you should see:
   ```
   $A,BOOT_SELF_TEST_DONE
   $C,mod=STAIR,fsw=500,bridge=BOTH,ffund=50.00,mi=0.95,cntoff=0,lock=OK
   $E,MODE_DEMOTED                         ← only if some sensors are absent
   $E,WARNING_OPEN_LOOP_NO_PROTECTION      ← only if no sensors present
   ```
   Followed by `$T,...` telemetry frames arriving at ~20 Hz.

4. Send `STATUS` — should get back one `$S,...` line summarising state.

5. Send `HELP` — should list all available commands including
   `MOD STAIR|PSC|STAIR_ALT`, `FSW`, `BRIDGE`, `FFUND`, `CONFIG`, `RESCAN`.

If you missed the 3 s window and see `$A,AUTO_START` followed by
`$A,RUN` — don't panic. With no power stages connected nothing is
energised. Send `STOP` to bring the FSM back to IDLE, then reset the
Nucleo if you want to start over.

**Verify before continuing:**
- [ ] `$C` line shows the expected STAIR / 500 / BOTH defaults.
- [ ] `lock=OK` in the `$C` line (will be `OK` for STAIR with `cntoff=0`).
- [ ] Telemetry arrives at ~20 Hz (visible in the dashboard plot).
- [ ] `STATUS`, `HELP`, `CONFIG` all respond.

If all four pass, the firmware is alive. Proceed to the
[Pre-bringup checklist](#pre-bringup-checklist) and then [Phase 1](#phase-1--continuity-no-power).

---

## Pre-bringup checklist

- [ ] [Step 0](#step-0--getting-the-firmware-onto-the-board) complete
      (branch flashed, dashboard connected, boot sequence verified).
- [ ] Build guide v3.1 Phase 1 (continuity check, no power) passed.
- [ ] ST-LINK VCP enumerated (Device Manager → Ports → STMicroelectronics
      STLink Virtual COM Port → note COM number).
- [ ] Terminal program ready as backup (PuTTY, Tera Term, or screen): 115200 8N1.
- [ ] Bench supplies set to current-limit mode, output OFF.
- [ ] **Auto-start awareness:** the firmware auto-issues `START` 3 s after
      boot if no UART byte has been received. Behavior by scenario:
      - **USB unplugged → auto-start fires** (standalone deployment).
      - **USB plugged, no PC software listening → auto-start fires** (USB
        is just powering the Nucleo).
      - **Dashboard connected → auto-start cancelled automatically.**
        The dashboard sends `STATUS` the moment it opens the serial port,
        which flips the firmware's `UART_ActivitySeen()` flag and blocks
        auto-start. You get full manual control.
      - **PuTTY / Tera Term connected but you don't type anything → auto-start
        fires after 3 s.** Type any character (or send a CR) to cancel.

---

## Phase 0 — Firmware sanity (just flashed, no power stages)

**Goal:** confirm firmware boots, UART works, sensors self-test correctly,
defaults are loaded.

**Setup:** Nucleo powered via USB only. Power stages disconnected (or
unpowered). No DC bus, no gate drive 15 V.

**Steps:**
1. Open dashboard (`py -3 dashboard/run_dashboard.py`) or terminal,
   connect to ST-LINK VCP at 115200 8N1.
2. Press the Nucleo's black reset button.
3. Within 3 s of boot, type any character (e.g. press Enter) to cancel
   auto-start. The dashboard's command pane does this implicitly when you
   click any button.

**Expected UART output within ~1 second of reset:**
```
$A,BOOT_SELF_TEST_DONE
$C,mod=STAIR,fsw=500,bridge=BOTH,ffund=50.00,mi=0.95
$E,MODE_DEMOTED                              ← only if some sensors absent
$E,WARNING_OPEN_LOOP_NO_PROTECTION           ← only if no sensors at all
$T,<ms>,IDLE,<mode>,0x00,<vdc1>,<vdc2>,<iout>,0*<chk>   ← starts at 20 Hz
```

If `$A,AUTO_START` appears: you missed the 3 s window. Send `STOP`
immediately, then reset.

**Verify:**
- [ ] `$C` line present and matches defaults exactly.
- [ ] `$T` telemetry frames arrive at ~20 Hz.
- [ ] `STATUS` command returns a single `$S,...` line with the same fields.
- [ ] `HELP` lists all commands including the new ones (`MOD`, `FSW`,
      `BRIDGE`, `FFUND`, `CONFIG`, `RESCAN`).
- [ ] If sensors connected: `vdc1`, `vdc2` show non-NAN values (DC bus is
      0 V, so expected ≈ 0 V — but with sensors floating you may see noise).
- [ ] No unexpected `$E,...` errors or `$F,...` faults.

**Troubleshooting:**
- **No UART output at all:** wrong COM port / wrong baud / ST-LINK VCP
  driver not installed.
- **Garbled UART output:** baud mismatch (must be 115200) or wrong UART
  framing (must be 8 data bits, no parity, 1 stop bit).
- **`$E,WARNING_OPEN_LOOP_NO_PROTECTION`:** none of the three MCP3201
  ADCs returned valid samples in self-test. Most likely the sensing
  island isn't powered yet (B0515S off) — that's expected at this phase.
- **`$E,MODE_DEMOTED`:** at least one ADC is missing/broken but others
  work. Continue — protection still works for available channels.
- **`$T` frames not arriving:** check FSM state — should be IDLE not
  BOOT. If stuck in BOOT, the sensing self-test hung (likely SPI wiring).

---

## Phase 1 — Continuity (no power)
Follow build guide section 6 Phase 1. No firmware involvement.

---

## Phase 2 — Gate drive test with external 15 V

**Goal:** confirm each TLP250 + MOSFET gate channel works individually,
*before* applying high voltage. Verifies pin assignments and dead-time.

**Setup:** Per build guide Phase 2. External 15 V bench supply (200 mA
limit) connected directly to **one bridge's** `+15V_Drive` and
`Drive_GND` rails, B0515S disconnected. Nucleo powered via USB. **No DC
bus voltage.**

**Strategy:** we use the per-bridge isolation feature (new on this branch)
to drive *only* the bridge under test, and run STAIR at the default
500 Hz so each gate has a clear, slow waveform on the scope.

### 2a. Bridge 1 channels

1. Reset Nucleo, immediately send any UART byte to cancel auto-start.
2. Send commands:
   ```
   MOD STAIR
   FSW 500
   BRIDGE B1
   MI 0.5
   START
   ```
3. Scope each of bridge 1's 4 MOSFET gates (Vgs, gate vs source):
   - **Q1 HS, Q3 HS:** should switch between ~0 V and +14–15 V at the
     50 Hz fundamental rhythm (NOT 500 Hz — STAIR holds each level for
     many PWM periods).
   - **Q2 LS, Q4 LS:** complementary to their HS partners. When HS is
     high, LS is low, and vice versa. Visible 3 µs dead-time on every
     transition.
4. Measure DC current draw from the 15 V supply: should be ~20–50 mA per
   bridge depending on switching activity.
5. `STOP` when done with bridge 1.

**Verify:**
- [ ] All 4 gates show clean square waves, no ringing, no missing edges.
- [ ] Dead-time visible on the LS-to-HS and HS-to-LS transitions (~3 µs).
- [ ] No simultaneous HS+LS on the same leg at any point (would be
      shoot-through).
- [ ] Bridge 2's gates (Q5–Q8) should be **silent** — all four sit in the
      freewheel state (HS off, LS on) for the entire test.

### 2b. Bridge 2 channels
1. `STOP`, `BRIDGE B2`, `START`.
2. Repeat the gate measurements on bridge 2's MOSFETs (Q5–Q8). Bridge 1
   should now be silent.

**Troubleshooting:**
- **A gate stays at 0 V even when its leg should be switching:** that pin
  is not actually driven by the firmware. Most likely wired to the wrong
  STM32 pin. Check against the actual firmware pin map:
  - PWM_1H = PA8 (TIM1_CH1), PWM_1L = PA7 (TIM1_CH1N)
  - PWM_2H = PA9 (TIM1_CH2), PWM_2L = **PA12** (TIM1_CH2N) ← guide says PA10, wrong
  - PWM_3H = PB6 (TIM8_CH1), PWM_3L = PB3 (TIM8_CH1N)
  - PWM_4H = PB8 (TIM8_CH2), PWM_4L = PB0 (TIM8_CH2N) ← guide says PC6–9, wrong
- **Gate switches but Vgs amplitude is <10 V:** bootstrap cap not charging.
  Check UF4007 orientation and the 10 µF cap.
- **HS and LS both high simultaneously (any duration):** dead-time
  failure → catastrophic shoot-through risk. Stop everything, check
  `PWM_DEAD_TIME_DTG` in [pwm_modulator.c](Core/Src/pwm_modulator.c).
- **Some bridge gates switch when `BRIDGE B1` is set:** bridge isolation
  bug. Send `CONFIG` to verify firmware actually got the `BRIDGE B1`
  command. Should report `bridge=B1`.

---

## Phase 3 — B0515S isolated supply test
Follow build guide section 6 Phase 3. No firmware involvement beyond
keeping the inverter in `IDLE` (i.e. send `STOP` if PRECHARGE/RUN is
active, or just don't `START`).

---

## Phase 4 — Sensing island + **MCP3201 decode verification**

**Goal:** confirm the bit-banged SPI is decoding ADC counts correctly.
This is where the `>> 3` vs `>> 1` question gets settled empirically.

**Setup:** B0515S supplies running (Phase 3 passed). DC bus terminals
accessible but bus capacitors NOT charged (or use a small bench supply,
NOT the 50 V rail).

**Steps:**
1. Reset Nucleo, cancel auto-start.
2. With DC bus at 0 V and current sensor unloaded, send `STATUS`.
3. Note the displayed `vdc1`, `vdc2`, `iout` values.
4. Apply a small known voltage to bridge 1's DC input — start with **5 V**
   from a bench supply (current-limited to 100 mA). `STATUS`.
5. Increase to 10 V, 20 V, 30 V in steps. `STATUS` at each step.

**Expected values:**

| Input | `vdc1` should read | If you see ~64 V instead |
|---|---|---|
| 0 V | 0.0–0.5 V (noise floor) | shift is `>> 1`, see fix below |
| 5 V | 4.7–5.3 V | shift is `>> 1` |
| 10 V | 9.5–10.5 V | shift is `>> 1` |
| 30 V | 29–31 V | shift is `>> 1` |

Resolution at the divider settings is ~0.25 V/count, so error of
~0.5 V at any value is normal.

**Verify:**
- [ ] `vdc1` tracks the bench supply linearly within ±5 %.
- [ ] `vdc2` similarly when you move the test supply to bridge 2's input.
- [ ] `iout` reads close to 0 A with no load (within ±0.5 A is normal
      for an unconnected ACS712 input).
- [ ] No new `$E,...` errors appear during the test.

**If the MCP3201 decode is wrong** (readings ~8× too high or stuck near
mid-scale):
1. Open [Core/Src/spi_mcp3201.c](Core/Src/spi_mcp3201.c) lines 132–150.
2. Change all three `>> 3` to `>> 1`.
3. Rebuild and re-flash.
4. Repeat Phase 4 — readings should now track input linearly.
5. Note this in CHANGELOG as guide section 7.3 documentation needing v3.2.

**Other failures:**
- **All three channels read the same value:** SPI MISOs are wired
  together or one MISO is shorting the others.
- **One channel reads NAN consistently:** that ADC's `available` flag
  went to 0 in self-test. Check its CS line and the 6N137 optocoupler
  for that channel. Send `RESCAN` after fixing.
- **Readings jitter wildly (±10 V):** ground loop. The sensing island
  ground (GND_Island) should be tied to the bridge's local floating
  ground via the 78L05 only — *not* to system ground.

---

## Phase 5 — Low-voltage power test (STAIR at 500 Hz, 10 V bus)

**Goal:** end-to-end test of the OLD bench-validated PWM path on the
fully assembled hardware, at a voltage low enough that mistakes don't
destroy anything.

**Setup:** Per build guide Phase 5. Both bridges' DC inputs at 10 V
(current-limited to 2 A). Load = 100 Ω resistor or 60 W incandescent
bulb in series with the ACS712.

> ⚠️ **Set `VNOM` to your test bus voltage before `START`.** The default
> protection thresholds assume a 50 V bus (UV = 40 V). At a 10 V test
> bus the firmware trips undervoltage immediately and never leaves
> PRECHARGE. `VNOM 10` rescales UV/OV/IMBAL to 8 / 11.6 / 2 V. This
> applies to every powered phase from here on — always match `VNOM` to
> the bus voltage you are about to apply.

**Steps:**
1. Reset Nucleo, cancel auto-start.
2. `VNOM 10` — rescale protection for the 10 V test bus. Confirm the
   `$P` line shows `uv=8.00,ov=11.60,imbal=2.00`.
3. `CONFIG` — confirm `mod=STAIR,fsw=500,bridge=BOTH,ffund=50.00,mi=0.95`.
4. `STATUS` — confirm both DC buses read ~10 V, iout ≈ 0 A.
5. `START`. Look for `$A,START`, then `$A,RUN` after ~6 ms precharge.
6. Scope the AC output (Node_X1 to Node_Y2) → expect a 5-level
   staircase swinging between roughly ±20 V at 50 Hz.
7. Watch telemetry. `iout` should swing sinusoidally with peak ~0.2 A
   (for 100 Ω load, 20 V/100 Ω = 0.2 A).
8. Run 5 minutes. Touch-test the bridge MOSFET heatsinks (with the back
   of your hand — never grip): you should already be able to feel that
   bridge 1's heatsink runs noticeably warmer than bridge 2's. **This is
   the concern #8 imbalance** that PSC fixes.
9. `STOP`.

**Verify:**
- [ ] AC output is a clean 5-level staircase, not 3-level (would mean
      one bridge isn't switching).
- [ ] No fault trips during the 5-minute run.
- [ ] `vdc1` and `vdc2` stay within 1 V of each other under load.
- [ ] Bridge 1's heatsink is warmer than bridge 2's (expected baseline
      to improve with PSC).

---

## Phase 6 — Single-bridge isolation test (new on this branch)

**Goal:** validate the `BRIDGE B1` / `BRIDGE B2` test mode. Use it to
characterize each bridge independently, e.g. when chasing a thermal
hotspot or a gate-drive marginality.

**Setup:** Same as Phase 5 (10 V bus, 100 Ω load).

**Steps for bridge 1 in isolation:**
1. `STOP` (if running).
2. `BRIDGE B1` — wait for `$A,BRIDGE B1` and `$C,...,bridge=B1,...`.
3. `START`.
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

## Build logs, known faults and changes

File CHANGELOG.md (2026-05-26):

# Repository Changelog

This changelog tracks the state of the **consolidated monorepo**. The firmware has its own changelog at [`firmware/stm32-f303re/CHANGELOG.md`](firmware/stm32-f303re/CHANGELOG.md) once imported.

## [Unreleased]

### Added
- Initial repository skeleton: directory tree, license, .gitignore, .gitattributes (Git LFS rules for large binaries), CITATION.cff.
- Build Guide v4.0 placed at `docs/hardware/build-guide-v4.md` (canonical engineering reference; supersedes v3.1).
- Agent tracking files: `_AGENT_TRACKER.md` (artifact checklist) and `_AGENT_HANDOVER.md` (populated in Phase 8).

### Pending (in-flight phases)
- Phase 1 — MkDocs Material site + GitHub Actions pipelines.
- Phase 2 — Firmware import via `git subtree` (history preserved).
- Phase 3 — KiCad project, gerbers, BOM, populated photos, scope captures.
- Phase 4 — Simulink model + THD/FFT analysis.
- Phase 5 — Design notes, iteration history, consolidated final report.
- Phase 6 — Experimental RISC-V SoC track.
- Phase 7 — Polish (front-door README, issue/PR templates, About pages).
- Phase 8 — Verification suite + handover document.

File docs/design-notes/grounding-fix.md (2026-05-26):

---
title: Grounding fix
---

# Grounding fix

<figure markdown="span">
  Top-down KiCad render — the iteration-4 layout that fixes the grounding issue
  <figcaption>The iteration-4 single-bridge module. The 4-layer stack-up keeps the controller-side and bridge-side grounds physically separated through the inner pours — exactly the fix this page documents.</figcaption>
</figure>

> **Single-sentence summary.** Iteration 3 of the PCB had a parasitic coupling between **5V_GND** (controller side) and **50V_GND** (bridge side) that defeated the isolation architecture. Iteration 4 fixed it through stricter layer separation and via placement on the 4-layer JLCPCB stack-up. The populated boards now run clean — confirmed by the team.

## The two grounds the project deliberately keeps separate

The CHB topology requires the controller side and each bridge side to be **galvanically isolated** ([see CHB isolation](chb-isolation.md)). The board uses three distinct reference nets:

| Net | Where it lives | Reference |
|---|---|---|
| **5V_GND** | STM32 Nucleo, USB / VCP, dashboard | System ground (USB shield-tied, ultimately mains-earth via the bench PC) |
| **50V_GND** (lower bridge) | Bridge 1 power stage, its TLP250 outputs, its MCP3201 | Floats at the lower-bridge DC source's negative rail |
| **50V_GND** (upper bridge) | Bridge 2 power stage, its TLP250 outputs, its MCP3201 + current MCP3201 | Floats at the upper-bridge DC source's negative rail (i.e. at Bridge 1's output node) |

These three nets are connected **only** through the isolation parts: TLP250 LED → photodetector, B0515S primary → secondary, 6N137 LED → photodetector. There is no copper trace, no via, no shared shield, no shared connector pin that bridges them on a correctly-designed board.

## What went wrong in iteration 3

The team's iteration-3 layout had two coupling paths between 5V_GND and 50V_GND that should not have been there. The combined effect was **measurable common-mode noise** on the controller's GPIO pins whenever Bridge 2 was switching at the cascade peak — exactly the failure mode that CHB isolation is supposed to prevent.

The specific issues (reconstructed from the bench notes and the iteration-3 KiCad backup; the team can fill in details):

1. **Shared via stitching across the isolation boundary.** A run of decoupling vias along the edge of the isolated island connected to the inner ground plane on layer 2 — which was a continuous 5V_GND pour. The intent was to give the isolated MCP3201 a clean decoupling return, but the via stitching effectively shorted the islands together at AC through the inner-layer pour.
2. **Insufficient creepage on the optocoupler footprints.** The 6N137 and TLP250 footprints had the input-side and output-side copper too close — a few mil at the closest point. Under the cascade-peak common-mode swing (50–100 V), the parasitic capacitance across that gap coupled enough current to make the SPI reads marginal.

The result was the kind of intermittent fault that's hard to diagnose: the dashboard's `STATUS` would occasionally show garbage ADC values, the firmware's `SENSOR_LOST` debounce would trigger sporadically, and switching from sustained run to PRECHARGE could leave the controller in a confused state.

## How iteration 4 fixed it

The fix was **physical separation**, not logical separation. Three changes:

### 1. 4-layer stack-up with dedicated, separated ground planes

Instead of a continuous inner ground plane, the iteration-4 stack-up uses **two separate inner pours**:

| Layer | Role |
|---|---|
| L1 (top, 1 oz) | Signal + power-stage traces. Routed in distinct **regions** for controller side vs. each bridge side, with no traces crossing the isolation boundary. |
| L2 (inner, 0.5 oz) | **5V_GND pour in the controller region only.** No copper extends into the isolated bridge regions. |
| L3 (inner, 0.5 oz) | **Per-bridge 50V_GND pours**, each in its own bridge region. No connection between them or to 5V_GND. |
| L4 (bottom, 1 oz) | Same regional split as L1. Isolated SPI return runs through the bridge-region copper only. |

This is the master plan rule "stitched ground vias along the boundary between primary and isolated regions" — the via stitching is now **within** each region (binding L1↔L2 in the controller region, L1↔L3 in each bridge region) and **never crosses** the isolation boundary.

### 2. Increased creepage at every isolation crossing

The TLP250, 6N137, and B0515S footprints in iteration 4 have **explicit keep-out regions** between the input-side and output-side pads. The DIP-8 packages physically span the boundary, so the routing on top and bottom layers around them is designed to maximize the creepage distance — typically 8–10 mm of cleared copper on both sides, no traces routed underneath.

This matters less for galvanic breakdown (the TLP250 is rated 2.5 kV; nothing on this bench gets close) and more for **parasitic AC coupling** across the part. The wider the gap, the smaller the parasitic capacitance, the less common-mode current flows when the bridge floats up to +50 V relative to the controller.

### 3. Single point of connection (intentionally)

Each bridge ground connects to its **own** isolated DC source's negative terminal — a single screw-terminal connection at the board edge. There is **no** intentional connection between bridge grounds, and no intentional connection from either bridge ground to 5V_GND. The only paths between any pair of these nets are through the isolation parts.

The current sense return is on the upper-bridge island ([see pin map](../firmware/pin-map.md) — MISO_CUR shares PC3 with MISO_DC2 on the same isolated MISO line). This was a layout-driven choice — keeping the current sense on the same island as DC2 means one shared 6N137 set instead of two.

## What "running clean" actually means

The team confirmed (per the user's notes during the pre-consolidation chat):

- **No false `SENSOR_LOST` events** during sustained PSC run at 5 kHz.
- **No `STATUS` corruption** on the dashboard over multi-minute sessions.
- **5-level cascade output visible on scope** at the demo with the dashboard simultaneously reporting clean telemetry.
- **Bridges thermally matched** under load — which would not be possible if either bridge had ADC reads going wrong, because the firmware's protection would have started tripping intermittently.

This is the test that an "isolation fix" actually has to pass: the system runs correctly under load, with the controller telemetry agreeing with what the scope shows. Iteration 4 passes it.

## What to remember

- Galvanic isolation is **not** automatic from picking the right ICs. Layout matters — a shared inner-plane via can defeat 2.5 kV-rated parts.
- The 4-layer stack-up is the cheapest single change with the biggest impact.
- Creepage between input and output pads on isolated parts matters even for parasitic AC coupling, not just for breakdown.
- The end test is: does the system stay correct under load? If telemetry is clean, ADC reads are stable, and protection doesn't false-trip, the grounding is right.

Related: [CHB isolation](chb-isolation.md), [stack-up details](https://github.com/feaksel/chb-inverter/blob/main/hardware/single-bridge-v4/stackup.md), [iteration history — iteration 3](../iteration-history/iteration-3.md).

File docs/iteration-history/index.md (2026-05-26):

# Iteration history

<figure markdown="span">
  Demo stand — the as-built iteration 4
  <figcaption>The as-built iteration 4 on the demo stand — what the project converged to after three earlier rounds.</figcaption>
</figure>

The story of the hardware as it evolved from the first board to the demonstrated design. Each page documents **what was attempted, what failed, what was learned, and what changed for the next round** — written honestly, with the failures in plain view rather than smoothed over.

| Iteration | Headline | Status |
|---|---|---|
| [Iteration 1](iteration-1.md) | Single dual-bridge PCB, IRFZ44N MOSFETs, IPD LS-PWM | Superseded |
| [Iteration 2](iteration-2.md) | Revised gate-drive routing; bootstrap-timing lessons | Superseded |
| [Iteration 3](iteration-3.md) | Per-bridge isolation, MISO topology rework, MOSFET pin-mismatch errata | Superseded |
| [Iteration 4](iteration-4.md) | Two identical single-bridge modules, IRFB4110, PSC-PWM | **As-built, bench-validated, demonstrated** |

## Why iterating like this matters

The project's headline result — **5 distinct cascade levels visible on the scope at 100 V output, both bridges thermally matched** — is not what iteration 1 produced. It took three rounds of bench-discovered failures and one re-architecture to reach.

Reading the four pages in order gives the engineering decisions in their original context: which assumptions were initially defensible, which broke under bench load, and which corrections compounded into the iteration-4 design. The [design notes](../design-notes/index.md) cover the *why* of specific decisions; this section covers the *when* and the *what triggered the change*.

## Where the artifacts live

| Iteration | What survives |
|---|---|
| Iteration 1 | [v3.1 BOM](https://github.com/feaksel/chb-inverter/blob/main/hardware/legacy/iteration-3/CHB_BOM_v3_1.xlsx) (under legacy/iteration-3/ for convenience). No KiCad files. |
| Iteration 2 | None preserved. |
| Iteration 3 | [KiCad zip backups](https://github.com/feaksel/chb-inverter/tree/main/hardware/legacy/iteration-3) (working tree + a mid-iteration snapshot). |
| Iteration 4 | Full KiCad project + gerbers + populated photos at [`hardware/single-bridge-v4/`](https://github.com/feaksel/chb-inverter/tree/main/hardware/single-bridge-v4). |

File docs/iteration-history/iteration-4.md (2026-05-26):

---
title: Iteration 4 — as-built (two single-bridge modules, IRFB4110, PSC)
---

# Iteration 4 — as-built (two single-bridge modules, IRFB4110, PSC)

<figure markdown="span">
  Five distinct cascade levels at 100 V — the iteration-4 demonstration result
  <figcaption>The iteration-4 deliverable on the scope — five distinct cascade output levels at 100 V under sustained PSC-PWM, no filter. Both bridges thermally matched, no protection trips during the run.</figcaption>
</figure>

> **Status:** as-built. **Bench-validated and demonstrated.** KiCad project at [`hardware/single-bridge-v4/kicad/`](https://github.com/feaksel/chb-inverter/tree/main/hardware/single-bridge-v4/kicad), gerbers at [`hardware/single-bridge-v4/gerbers/`](https://github.com/feaksel/chb-inverter/tree/main/hardware/single-bridge-v4/gerbers), photos at [`hardware/single-bridge-v4/photos/`](https://github.com/feaksel/chb-inverter/tree/main/hardware/single-bridge-v4/photos) and `docs/assets/images/` (demo day).

## What was attempted

Iteration 4 was a **rebuild from the iteration-3 lessons** rather than a tweak on top of iteration 3. Six structural changes:

| Change | From | To | Rationale |
|---|---|---|---|
| Board topology | Single dual-bridge PCB | **Two identical single-bridge PCB modules** | Modularity; each cell can be bench-tested in isolation; bridges become interchangeable. |
| Stack-up | 2-layer | **4-layer, 1.6 mm FR-4, JLCPCB** | Dedicated ground planes solve the [5V_GND ↔ 50V_GND coupling](../design-notes/grounding-fix.md) from iteration 3. |
| Power MOSFET | IRFZ44N (55 V) | **IRFB4110 (100 V, 4.5 mΩ)** | V<sub>DSS</sub> headroom; resolves the TVS clamp / MOSFET breakdown mismatch from iteration 1. |
| Modulator | IPD LS-PWM at 500 Hz | **PSC-PWM at 5 kHz** | Bridge-thermal symmetry; better filter behavior; better textbook THD. |
| Dead time | 2 µs (IRFZ44N) | **3 µs (`BDTR.DTG = 0xA0`)** | Compensates for the IRFB4110's ~2× gate charge. |
| MISO topology | 3-independent assumption | **2 MISO lines (lower-island dedicated, upper-island shared DC2 + CUR)** | Reflects the actual as-fabricated routing. Firmware rewritten to sequential one-CS-at-a-time reads. |

The firmware that drives this hardware lives on the [`pwm-rewrite-configurable`](https://github.com/feaksel/5-Level-Cascaded-H-bridge-Inverter-with-STM32-Nucleo-F303RE/tree/pwm-rewrite-configurable) branch — imported into this repo via `git subtree` with full history.

## What worked

The bench validation confirmed every headline goal:

| Goal | Result |
|---|---|
| **5 distinct cascade output levels visible on scope** | ✅ — see the `scope-pwm-cascade-output.jpeg` capture in [populated photos](../hardware/populated-photos.md). |
| **PSC carrier phase lock** | ✅ — `$C,...,lock=OK` reported on every config line and across runs. |
| **Bridges thermally matched** | ✅ — within ~3 °C under sustained PSC load. |
| **Sensing clean throughout the run** | ✅ — no false `SENSOR_LOST` events, `STATUS` line clean over multi-minute sessions. |
| **Dashboard auto-cancels firmware auto-start** | ✅ — `STATUS` echoed on connect and on every `BOOT_SELF_TEST_DONE`; operator always in control when the dashboard is open. |
| **Protection chain protects** | ✅ — TVS clamps below MOSFET V<sub>DSS</sub>; UV/OV/OC/IMBAL with N-of-M debounce; FAULT_OUT pin pulled LOW on trip. |

## What's still soft (carries over to the [roadmap](../roadmap/index.md))

- **No LC output filter.** The bench demo ran into a resistive load. For non-trivial loads, [the LC filter](../roadmap/lc-filter.md) is the next item.
- **Open-loop control.** Modulation index is set by the operator. [Closed-loop control](../roadmap/closed-loop-control.md) is the natural follow-on.
- **No enclosure.** Open-bench operation only. See [thermal enclosure](../roadmap/thermal-enclosure.md).
- **Bench-only verification.** No compliance testing, no grid-side integration. See [grid tie](../roadmap/grid-tie.md) and [product path](../roadmap/product-path.md).

## What to remember about iteration 4

- It is **not** an incremental fix to iteration 3 — it's a re-architecture motivated by what the earlier iterations made painful.
- The modular two-PCB-module decision is the most important structural choice; everything else hangs off it (interchangeable boards, single fab order, simpler bring-up procedure).
- The IRFZ44N → IRFB4110 swap is the kind of mid-project component change that needs the firmware (dead time) and the protection chain (TVS clamp vs. MOSFET V<sub>DSS</sub>) to be updated together. Both were.
- The PSC carrier-shift lock diagnostic was added defensively before the bench session — it caught a real issue on day one and saved an afternoon of scope time.

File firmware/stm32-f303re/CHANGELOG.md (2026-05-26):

# Changelog

All notable changes to the 5-Level Cascaded H-Bridge Inverter firmware and the
companion PC dashboard. Loosely follows [Keep a Changelog](https://keepachangelog.com/en/1.1.0/).
Versions are tagged to commits in the repo; pre-release versions track the
state of `main` at that point in time.

Each release lists what changed and the design decisions that were made along
with the change, so a reader can reconstruct *why* the code looks the way it
does without having to dig through the diff.

---

## [0.5.0-dev] — branch `pwm-rewrite-configurable` — PSC-PWM + runtime config

Branched from `main` at commit `f5ff93f` (the reverted-MCP3201-shift state).
Adds a second modulator alongside the bench-validated STAIR, makes the PWM
runtime-configurable from UART/dashboard, and adds an auto-start path so
the system runs standalone with safe defaults when no UART is connected.

### ADCRAW diagnostic + manual TRIP command
Two bringup-support commands added after the PCB sensing came up dead:

- **`ADCRAW`** — does one raw MCP3201 read and reports the actual 12-bit
  counts (`$R,dc1=N,dc2=N,cur=N`, 0..4095) instead of only the
  available/unavailable verdict. Lets the operator see whether a MISO
  line is stuck (constant 4095/0) or actually carrying data, without a
  scope. Honors the current `SPIINV` mask. Allowed in any state.
- **`TRIP`** — operator-forced fault. Latches a new `FAULT_MANUAL`
  (0x20) bit, enters the FAULT state, disables PWM, and drives the
  FAULT_OUT pin low — exactly like a real protection trip. Lets the
  FAULT behavior and the FAULT_OUT hardware pin be demonstrated even
  when the sensors are not yet readable (so no real UV/OV/OC trip can
  be produced). Allowed from IDLE / PRECHARGE / RUN; `CLEAR` exits it
  normally. New dashboard button "FORCE FAULT". `FAULT_MANUAL` shows as
  `MANUAL` in `$F` fault reports and the dashboard fault badge.

### Runtime-configurable SPI line inversion (SPIINV)
During PCB bringup the sensing came up dead (all channels OPEN) even with
the island powered. Root-cause candidate: the 6N137 optocouplers on the
SCK / CS / MISO lines **invert** (LED on → output low), and the firmware
drove/read those lines as if directly connected — so the MCP3201 saw an
inverted clock, a backwards chip-select, and inverted data.

Rather than hard-code a polarity, the inversion is now **runtime
configurable** so it can be flipped from the dashboard without reflashing
per attempt:
- **`SPIINV <0..7>`** UART command / **Set SPIINV** dashboard control.
  Bitmask: bit 0 = SCK, bit 1 = CS, bit 2 = MISO. `0` = direct drive
  (unchanged default), `7` = all inverted (standard one-6N137-per-line
  wiring).
- Setting it **auto-runs the ADC self-test** (same follow-up as `RESCAN`)
  so the operator sees at once whether the sensors come alive.
- Allowed in IDLE or FAULT.
- The active mask appears in the `STATUS` line as `spiinv=0xN`.
- `SPI_DEFAULT_INVERT_MASK` in [spi_mcp3201.h](Core/Inc/spi_mcp3201.h)
  sets the power-on default — leave at 0 until the bench confirms the
  inverted mode, then set to 7.

Firmware: [spi_mcp3201.c](Core/Src/spi_mcp3201.c) gains invert-aware
`sck_idle`/`sck_active`/`cs_select`/`cs_deselect` helpers and a per-bit
MISO read inversion; `SPI_MCP3201_SetInvert`/`GetInvert` accessors;
[fsm.c](Core/Src/fsm.c) `handle_spiinv`; STATUS line `spiinv=` field.
Dashboard: SPIINV combo in the controls panel, sim setter, 2 new tests
(27 total, all passing).

### MISO topology change (2 shared lines) + hardware FAULT_OUT pin
User's PCB does not match the firmware's original 3-independent-MISO
assumption. The actual board has **two** MCP3201 data-return lines:
- Lower-bridge island: DC1 ADC alone on its own MISO (PA6).
- Upper-bridge island: DC2 ADC **and** the current ADC wire-share one
  isolated MISO return (PC3). Each ADC keeps its own chip select.

The original `SPI_MCP3201_Read` asserted all selected chip-selects
together and read three separate MISO pins in parallel — on this board
that would put the DC2 and current MCP3201 DOUTs onto the same wire
simultaneously. Rewritten ([spi_mcp3201.c](Core/Src/spi_mcp3201.c)) to
a strictly **sequential one-channel-at-a-time read**: exactly one CS is
asserted per 16-clock pass, so DC2 and CUR are never selected together.
This also matches the read sequence described in build guide v3.1
section 3.6.2. Slower (~3× the read time) but negligible at the 1 kHz
sense rate. `config.h` MISO_CUR pin moved from PC4 to PC3 (shared with
DC2); PC4 is now unused.

**Hardware FAULT_OUT pin added** ([config.h](Core/Inc/config.h),
[main.c](Core/Src/main.c), [fsm.c](Core/Src/fsm.c)). PB5 is configured
as a push-pull output, active-low: the FSM drives it LOW in
`enter_fault` and HIGH in `enter_idle`. Corresponds to build guide
v3.1 header pin 16 "FAULT_OUT". Drives an indicator LED or an external
interlock. Faults are still also reported over UART (`$F` lines) as
before — the GPIO is an addition, not a replacement.

### Protection thresholds runtime-configurable (VNOM / OC)
User pointed out they don't always run 50 V per bridge — bench tests
often run at 12 V or other low voltages. With the original fixed 40 V
undervoltage threshold, a 12 V bus trips UV instantly and the inverter
can never leave PRECHARGE. Low-voltage testing was effectively
impossible without disabling protection entirely (OPEN mode).

Fixed by making the DC-bus protection thresholds derive from a single
runtime-settable nominal bus voltage:
- **`VNOM <v>`** (UART) / **Set VNOM** (dashboard) — sets the nominal
  per-bridge bus voltage, 5–60 V. The firmware derives UV = 0.80·VNOM,
  OV = 1.16·VNOM, IMBAL = 0.20·VNOM. At VNOM = 50 these reproduce the
  original 40 / 58 / 10 V design values exactly.
- **`OC <a>`** (UART) / **Set OC** (dashboard) — overcurrent trip,
  0.5–20 A, independent of VNOM (it is a load property, not a bus
  property).
- Both allowed in IDLE or FAULT (FAULT included so an operator who
  tripped UV at low voltage can set VNOM and then CLEAR).
- New `$P,vnom=...,uv=...,ov=...,oc=...,imbal=...` telemetry line,
  emitted at boot, on any VNOM/OC change, and on `CONFIG`.

Firmware: [protection.h](Core/Inc/protection.h) /
[protection.c](Core/Src/protection.c) thresholds converted from
compile-time `#define`s to runtime variables with `Protection_Set*` /
`Protection_Get*` accessors; [uart_telem.c](Core/Src/uart_telem.c) adds
the `VNOM`/`OC` parser and `UART_SendProtectionConfig`;
[fsm.c](Core/Src/fsm.c) adds `handle_vnom` / `handle_oc` and emits `$P`.

Dashboard: `Set VNOM` / `Set OC` controls in the PWM-config panel; the
simulator's sensor model and fault logic now scale with VNOM so PC-only
demos stay consistent at any nominal voltage; `protocol.py` recognises
the `$P` line; 5 new sim tests (25 total, all passing).

### Dead-time raised to 3 µs for the IRFB4110 power stage
User clarified the actual MOSFETs are **IRFB4110** (100 V, 180 A, 4.5 mΩ),
not the IRFZ44N (55 V, 49 A, 17.5 mΩ) listed in build guide v3.1's BOM.

Two consequences:
- **Dead-time increased from 2 µs to 3 µs** ([pwm_modulator.c](Core/Src/pwm_modulator.c)).
  The IRFB4110 has roughly 2× the gate charge (~150 nC vs ~67 nC), so with
  the same TLP250 + 22 Ω gate resistor the turn-on/turn-off transitions
  take about twice as long. The OLD 2 µs value (bench-validated for
  IRFZ44N) no longer leaves enough shoot-through margin. New value is
  `TIM_DTG_3US_AT_64MHZ` (`BDTR.DTG = 0xA0`). Added named DTG constants
  for 2/3/4 µs so the value is easy to adjust. At 5 kHz PWM, 3 µs is
  1.5 % of the period — negligible output-amplitude cost.
- **The 1.5KE62A TVS (84.5 V clamp) is now correctly matched.** With the
  100 V IRFB4110 the TVS clamps spikes well below breakdown. With the
  55 V IRFZ44N the same TVS would have let the FET see 84.5 V — over
  its rating. The IRFB4110 choice resolves that latent BOM hazard.

Docs updated: README key-parameters, HARDWARE_BRINGUP (scope-expected
dead-time, FSW-sweep note, shoot-through troubleshooting escalates
3→4 µs now), FIRST_BENCH_SESSION (same).

### Dashboard auto-cancels firmware auto-start while connected
User asked: "if no UART, only the dashboard isn't connected, right?"
Almost — but the original implementation had an edge case where the
dashboard could be connected purely for monitoring and the firmware's
3 s auto-start would still fire because nothing was actually sending
bytes to USART2 RX.

Fixed by having the dashboard's `SerialSource` automatically transmit
`STATUS` in two places:
- **On serial port connect** (`SerialSource.connect_port`): one-shot
  query the moment the COM port opens. Flips `UART_ActivitySeen()` on
  the MCU before the 3 s window can elapse.
- **On every detected `$A,BOOT_SELF_TEST_DONE`** in the RX stream
  (`SerialSource._handle_line`): re-sends `STATUS` so that resetting
  the Nucleo while the dashboard is connected does NOT let auto-start
  fire on the new boot cycle. (Without this, the MCU's
  `UART_ActivitySeen()` flag is cleared by the reset and a fresh 3 s
  window would start.)

Result — the firmware's standalone auto-start path now behaves exactly
as the user wants:
- USB unplugged → auto-start fires (standalone deployment).
- USB plugged, no PC software listening → auto-start fires (USB just
  powering the Nucleo).
- Dashboard connected → auto-start cancelled, full operator control,
  resilient across Nucleo resets.
- PuTTY / Tera Term connected but operator idle → auto-start fires
  after 3 s (typing any character cancels).

The TX log shows `STATUS (auto-cancel)` and
`STATUS (auto-cancel post-reset)` events so the cancellation is
visible in the audit trail.

### Updates after user feedback on STAIR being "fake PWM"
User correctly identified that the OLD STAIR modulator is **not real PWM** —
it's static level selection where each of 5 levels is held for 2 ms with
only 1 % bootstrap-refresh "switching." Since the project deliverable is
5 distinct cascade levels visible on a scope **without** an output LC
filter, the PSC modulator's 90° carrier phase shift escalates from
"nice to have" to **mandatory** — without it, PSC degrades to 3-level
output which fails the project spec.

Three changes added in response:

- **`MODULATOR_STAIR_ALT`** ([pwm_modulator.c:stair_alt_modulate](Core/Src/pwm_modulator.c)).
  Same staircase output as STAIR (so 5 levels are trivially visible)
  but the bridge that carries the ±1 step alternates each time the
  level is re-entered. Fixes the thermal imbalance without changing
  the visible output shape. Still NOT real PWM — used as a hard-fallback
  if PSC's 90° shift cannot be made to work on hardware.
- **PSC phase-shift hardening** ([pwm_modulator.c:timer_apply_period_and_phase](Core/Src/pwm_modulator.c)).
  TIM8->CNT is now written AFTER `CR1_CEN` is set (post-UG sequence
  cannot clobber it). The actual TIM8-TIM1 counter offset is read
  back, compared to the expected ARR/2, and exposed as two new
  diagnostics: `g_pwm_measured_cnt_offset` (ticks) and
  `g_pwm_phase_locked` (0/1).
- **`$C` config line now reports phase-lock**:
  `$C,...,cntoff=<ticks>,lock=OK|BAD`. Operator sees instantly whether
  PSC will actually produce 5-level output without needing a scope.

### Added
- **`pwm_modulator.c/h` + `pwm_config.h`** — new module that owns all
  PWM-related state: sine LUT, phase accumulator, period, precharge counters,
  modulator dispatch, timer reconfig, both modulator implementations. The
  TIM1 update IRQ handler now lives here as `Pwm_TIM1_UpdateHandler`; the
  bare-metal init in [main.c](Core/Src/main.c) just calls `Pwm_Init()`.
- **PSC modulator** — unipolar phase-shifted-carrier SPWM at the configured
  switching frequency. TIM8 CNT preset to `PWM_PERIOD/2` at config time gives
  the 90° carrier shift required for natural 5-level output from two
  cascaded cells. Same precharge sequence, same fault-trip path, same
  telemetry as STAIR. Bridge 1 and bridge 2 carry equal switching load — the
  point of the rewrite.
- **STAIR modulator** — the bench-validated 500 Hz quantize-to-5-levels
  implementation, moved verbatim from `main.c` into `pwm_modulator.c`. The
  duty math, `quantize_5level`, `bridge_level_to_duty`, and the precharge
  sequence are byte-for-byte the OLD code. Selectable at runtime so you can
  A/B compare against PSC on the bench without reflashing.
- **Runtime PWM configuration** ([pwm_config.h](Core/Inc/pwm_config.h)) with
  safe defaults that match the OLD bench-validated PWM (STAIR / 500 Hz /
  BOTH / MI 0.95 / 50 Hz fundamental). All settable in IDLE via UART.
- **New UART commands** (with dashboard buttons/dropdowns to match):
  - `MOD STAIR|PSC` — pick modulator algorithm
  - `FSW <hz>` — switching frequency (100..20000 Hz)
  - `BRIDGE BOTH|B1|B2` — single-bridge test mode (the inactive bridge is
    driven into freewheel so its contribution to the cascaded output is 0 V;
    the active bridge produces its normal 3-level swing)
  - `FFUND <hz>` — fundamental frequency (10..400 Hz)
  - `CONFIG` — print the current `$C,mod=...,fsw=...,bridge=...,ffund=...,mi=...`
    line; also emitted on every config change for the dashboard log
  - `HELP` updated to list all new commands
- **Auto-start path** ([fsm.c](Core/Src/fsm.c)). If no UART byte is received
  within `PWM_AUTOSTART_DELAY_MS = 3000 ms` after `FSM_Init` completes, the
  FSM issues its own START using the loaded defaults and emits
  `$A,AUTO_START` so any later-attached dashboard sees the event. Any UART
  RX byte cancels auto-start permanently — operator presence overrides
  standalone behavior. Detection uses `UART_ActivitySeen()`, which is set
  in the USART2 RX IRQ on any byte (not just valid commands).
- **Bridge isolation in both modulators** — `BRIDGE_B1_ONLY` forces bridge 2
  into freewheel state (both legs at LOW clamp duty, contribution ≈ 0 V) and
  vice versa. Active bridge produces 3-level (−Vdc / 0 / +Vdc) output.
- **Dashboard PWM Config panel** — `MOD`/`FSW`/`BRIDGE`/`FFUND` controls
  inside the existing Controls group, plus a `CONFIG` button. `FSW` is a
  presets dropdown (500 / 1000 / 2000 / 5000 / 10000 Hz) with free-form
  custom-value input. Bottom panel grown to 220–360 px to fit.
- **Sim controller stubs** for all new commands ([sim.py](dashboard/visual_twin_dashboard/sim.py))
  so scenario playback continues to mirror firmware behavior; 4 new unit
  tests verify the config-change happy path, range rejection, IDLE-only
  gating, and the `config_summary()` formatting.

### Changed
- **`main.c` slimmed from 367 → 122 lines.** Everything PWM-related moved
  to `pwm_modulator.c`. `main.c` now owns only: clock config, GPIO setup,
  NVIC priorities, SysTick, and `main()` itself.
- **TIM1_UP_TIM16 IRQ handler** ([stm32f3xx_it.c](Core/Src/stm32f3xx_it.c))
  now calls `Pwm_TIM1_UpdateHandler` instead of the old `PWM_Update_IRQHandler`.
- **`MI` command** routes through the new lightweight `Pwm_SetModulationIndex`
  helper so the cached config struct stays in sync with `g_pwm_modulation_index`
  without triggering an unnecessary timer reconfig.
- **`FSM_Init`** now emits a `$C` config line right after `BOOT_SELF_TEST_DONE`
  so any dashboard connecting on boot sees the active PWM configuration
  immediately without having to issue `CONFIG`.

### Decisions
- **Two modulators behind a runtime switch, not a build-time flag.**
  Lets the user A/B test on the same bench session without reflashing,
  and keeps the "known-good fallback" property of STAIR while PSC is
  being characterised. The dispatch is a single `if` at the bottom of
  `Pwm_TIM1_UpdateHandler` — negligible ISR overhead.
- **All PWM state lives in `pwm_modulator.c`, including the OLD STAIR
  globals (`g_precharge_ticks`, etc.).** Originally these were in `main.c`
  and `fsm.c` accessed them via extern. Centralising in the modulator means
  `main.c` becomes just system bring-up, and timing-critical state has one
  owner. `fsm.c` still uses extern declarations for the precharge handshake.
- **STAIR is moved, not duplicated.** The OLD STAIR ISR logic is moved
  verbatim into `stair_modulate()` in `pwm_modulator.c` — quantize, level
  mapping, duty clamp, CCR writes are byte-for-byte the same as the
  bench-validated `main.c` ISR. The only additions are: (a) reading
  `g_pwm_period` instead of the `PWM_PERIOD` macro, so FSW can change at
  runtime; and (b) the `g_pwm_bridge_select` check after the level
  computation to support single-bridge test mode.
- **PSC carrier phase shift via TIM8 CNT preset, not via slave-mode
  triggering.** Simpler and good enough — both timers share a clock, so
  once the offset is set at `Pwm_SetConfig` time they stay locked. Slight
  drift over many hours is theoretically possible but the LUT-driven sine
  re-aligns the phase relationship every fundamental period anyway.
- **PSC uses 0.05/0.95 duty clamps; STAIR keeps 0.01/0.95.** PSC actively
  modulates both legs symmetrically, so both clamps bind. STAIR's "off"
  leg sits at ~1% duty (HS almost off, LS almost on) — bootstrap is fine
  on that leg, the 5% rule only constrains the "on" leg's HS.
- **Auto-start fires regardless of sensing mode.** Even if the mode
  auto-demoted to `OPEN_LOOP` (no sensors connected), auto-start still
  fires after 3 s with a UART warning ("$E,WARNING_OPEN_LOOP_NO_PROTECTION"
  follows the "$A,AUTO_START"). The alternative — blocking auto-start in
  OPEN — would defeat the standalone-demo use case. The "no UART = no
  operator" assumption is the safety boundary; the operator who deployed
  the firmware without sensors accepted the OPEN risk.
- **`Pwm_SetConfig` always reconfigures the timer**, even for fields that
  don't affect the timer (like `bridge_select` or `modulation_index`).
  Simpler than tracking which fields changed. A reconfig in IDLE is
  invisible to the operator (MOE off, no output disruption) and cheap
  (~20 instruction cycles plus EGR_UG). The `Pwm_SetModulationIndex`
  helper exists only because `MI` is a hot path the operator may tweak
  repeatedly during bringup.
- **Bridge isolation = freewheel, not high-Z.** The inactive bridge's
  outputs are driven to LOW duty (both HS off, both LS on, ≈99% of period),
  which holds its terminals at the bridge's local 0 V. Net contribution to
  the cascaded output is 0 V. Alternative — disabling the timer outputs
  entirely (CCxE=0) — would let the output float and let body diodes
  potentially conduct, which is worse than a controlled freewheel.
- **Telemetry `$T,...` format unchanged.** Dashboard parser still works
  with no modification. New PWM-config information rides on the existing
  `$S,...` STATUS line (and the new `$C,...` config line). This keeps
  v0.3.0 dashboards forward-compatible with this firmware — they'll just
  ignore the `$C` line.

### Known-issue impact
- **Bridge 1 thermal/current imbalance** (the headline reason for this
  branch) — fix path: switch to `MOD PSC` at runtime. Bench validation
  step is to run STAIR for 5 min, measure both bridges' MOSFET case temps,
  then switch to PSC for 5 min and re-measure; they should converge to
  within ~3 °C. If they do, this branch is the win and the guide's IPD
  recommendation can be updated to PSC in v3.2.
- **HAL cleanup** still deferred — orthogonal to this branch.

### Bringup sequence on this branch
A full phase-by-phase procedure with what-to-expect, scope captures, and
troubleshooting lives in [HARDWARE_BRINGUP.md](HARDWARE_BRINGUP.md). High-level:
1. Boot emits `$A,BOOT_SELF_TEST_DONE` + `$C` config line + (if applicable)
   `$E,MODE_DEMOTED` + (if applicable) `$E,WARNING_OPEN_LOOP_NO_PROTECTION`.
2. Send any UART byte within 3 s to cancel auto-start; otherwise look for
   `$A,AUTO_START`.
3. `CONFIG` → STAIR baseline → measure thermals → switch to PSC → re-measure.
4. Per-bridge isolation tests with `BRIDGE B1` / `BRIDGE B2`.
5. If PSC checks out, flip `PWM_DEFAULT_MODULATOR` in
   [pwm_config.h](Core/Inc/pwm_config.h) to `MODULATOR_PSC` and merge to `main`.

### Build verification (2026-05-16)
Compiled and linked locally using STM32CubeIDE 1.17's bundled toolchain
(`arm-none-eabi-gcc 12.3.1`, the same compiler the IDE invokes) so the
branch is known-good before any bench bringup:

```
Build flags (matches .cproject):
  -mcpu=cortex-m4 -mfpu=fpv4-sp-d16 -mfloat-abi=hard -mthumb
  -DDEBUG -DUSE_HAL_DRIVER -DSTM32F303xE
  -ICore/Inc -IDrivers/STM32F3xx_HAL_Driver/Inc/Legacy
  -IDrivers/STM32F3xx_HAL_Driver/Inc
  -IDrivers/CMSIS/Device/ST/STM32F3xx/Include -IDrivers/CMSIS/Include
  -O0 -g3 -Wall -Wextra -Wshadow -Wundef
  -ffunction-sections -fdata-sections

Link flags:
  -TSTM32F303RETX_FLASH.ld -Wl,--gc-sections -static
  --specs=nano.specs --specs=nosys.specs -u_printf_float
  -Wl,--start-group -lc -lm -Wl,--end-group
```

Result: 11 Core/Src .c files + 14 HAL drivers + startup.s → ELF
35.5 KB code / 468 B data / 3.7 KB BSS. Total Flash 36 KB of 512 KB
available, total RAM 4.1 KB of 64 KB. **Zero warnings** under the strict
warning set above.

`nm` against the linked ELF confirms every new symbol from this branch
is present and resolved:
- `Pwm_TIM1_UpdateHandler`, `Pwm_Init`, `Pwm_SetConfig`, `Pwm_GetConfig`,
  `Pwm_SetModulationIndex`, `Pwm_HandlePrechargeStep`,
  `Pwm_ParseModulator`, `Pwm_ParseBridgeSelect`, `Pwm_ModulatorName`,
  `Pwm_BridgeName`, `psc_modulate`
- `do_start`, `handle_mod`, `handle_bridge`, `handle_fsw`, `handle_ffund`,
  `emit_pwm_config_line`, `g_auto_start_done`
- `UART_ActivitySeen`, `UART_SendPwmConfig`
- All global config state defined exactly once
  (`g_pwm_modulator`, `g_pwm_bridge_select`, `g_pwm_period`, etc.)

Flashable artifacts produced under `build/`:
- `5levelchb.elf` — debug symbols for CubeIDE/gdb (1.07 MB)
- `5levelchb.bin` — raw binary for drag-and-drop to the Nucleo's USB
  mass-storage drive (36.5 KB)
- `5levelchb.hex` — Intel HEX for ST-LINK Utility / STM32CubeProgrammer
  (100 KB)
- `5levelchb.map` — link map for symbol/section debugging (445 KB)

### Dashboard test verification
19 / 19 unit tests pass — the 15 pre-existing protocol + sim tests plus
4 new tests in [dashboard/tests/test_sim.py](dashboard/tests/test_sim.py)
covering:
- Default PWM config values match firmware defaults.
- Each setter (`set_modulator`, `set_bridge`, `set_switching_freq`,
  `set_fundamental_freq`) updates state and returns the expected ack string.
- Out-of-range values return the correct error string.
- All four setters reject when not in IDLE.
- `config_summary()` format matches what the firmware emits on `$C`.

Run from `dashboard/`:
```
py -3 -m unittest discover tests -v
```

---

## [Unreleased] — 2026-05-16 — Pre-bringup fixes + build-guide cross-reference

End-to-end review of the firmware before applying high voltage, followed by
a parameter-by-parameter cross-reference against the team's official build
guide v3.1 (`CHB_Inverter_Build_Guide_v3_1.pdf`, dated February 2026).

PWM generation in [main.c](Core/Src/main.c) was deliberately left untouched
because the 500 Hz quantize-staircase modulator was bench-validated in an
earlier session. The decision to replace it with PSC-PWM (deviating from
the guide's documented IPD LS-PWM) is captured under "Decisions" below and
will land in a dedicated branch.

### Fixed
- **Status line and telemetry line disagreed on "sensor valid"**
  ([uart_telem.c:449-454](Core/Src/uart_telem.c#L449)). `UART_SendStatus`
  used `channel.initialized` (sticky once true), while `UART_SendTelemetry`
  used `channel.available` (can flip back to 0 when a sensor goes lost).
  A sensor that booted OK and later disappeared would still show a stale
  number in `STATUS` but `NAN` in telemetry. Both now use `available`.

### Changed
- **Duty cycle clamp tightened to 95% per build guide v3.1 section 7.4**
  ([main.c:30-34](Core/Src/main.c#L30-L34)). `DUTY_HIGH_CLAMP` reduced from
  `0.99f` to `0.95f`. Ensures the low-side gets ≥5% on-time per period to
  refresh the bootstrap cap (UF4007 + 10 µF). Output amplitude drops by
  ~4% (50 V bus → +47.5 V max bridge contribution instead of +49.5 V).
  `DUTY_LOW_CLAMP` left at `0.01f` — that clamp constrains the opposite
  leg whose LS is already on ~99% of the period and is not bootstrap-bound.

### Reverted
- **MCP3201 bit-shift change.** In an earlier pass the shift was changed
  from `(raw >> 3) & 0x0FFF` to `(raw >> 1) & 0x0FFF` based on one
  interpretation of the MCP3201 datasheet's 1.5 SCK sample window. The
  build guide section 7.3 documents `(raw >> 3) & 0x0FFF` with the bit
  layout `[NULL][B11..B0][X][X][X]` — i.e., NULL at the 1st rising edge
  sample. Reverted to match the guide. The driver now contains a
  bringup-verification comment ([spi_mcp3201.c:132-145](Core/Src/spi_mcp3201.c#L132-L145))
  explaining how to swap to `>> 1` if the bench reading at a known DC
  input (e.g. 5 V → expected raw ~199) comes back ~8× off.

### Added
- **N-of-M debounce on protection trips** ([protection.h:14-17](Core/Inc/protection.h#L14-L17),
  [protection.c](Core/Src/protection.c)). Each fault bit (UV, OV, OC, IMBAL)
  has its own consecutive-hit counter. A fault must be observed in
  `PROTECTION_TRIP_COUNT = 3` back-to-back 1 kHz sensor scans before it
  trips. Any clean read resets the counter. Counters are also zeroed in
  `Protection_ClearLatched` so re-entering RUN after a CLEAR starts fresh.
  Trip latency is 3 ms — guide section 5 documents "~1 ms" target, the
  3 ms is a conscious trade for noise rejection during bringup.
- **`RESCAN` UART command** ([uart_telem.h](Core/Inc/uart_telem.h),
  [uart_telem.c](Core/Src/uart_telem.c),
  [fsm.c:181-199](Core/Src/fsm.c#L181-L199)). Re-runs `Sensing_SelfTest`
  to re-mark sensors available after a transient loss without rebooting
  the board. Allowed in `IDLE` and `FAULT` only. If the current mode's
  required sensors are still missing afterwards, auto-demotes to the
  best available mode and emits `MODE_DEMOTED`. Updates the help string.
- **Dashboard `RESCAN` button** ([app.py](dashboard/visual_twin_dashboard/app.py),
  [sim.py](dashboard/visual_twin_dashboard/sim.py),
  [sources.py](dashboard/visual_twin_dashboard/sources.py)). Live serial
  sends `RESCAN` to the firmware. Simulator clears the `sensor_lost`
  scenario flag so the PC twin mirrors the firmware behavior.

### Removed
- `CONFIG_PRECHARGE_TIMEOUT_MS` from [config.h](Core/Inc/config.h). Defined
  in the FSM commit but never referenced.

### Verified (no code change)
- **TLP250 gate driver polarity** (concern #10 in the review). The TLP250
  is non-inverting (LED ON → output HIGH → MOSFET ON). Confirmed by user
  and consistent with build guide section 3.3.2 (controller PWM pin →
  220 Ω → pin 2 anode, pin 3 cathode → GND_System — i.e., source config).
  With BDTR `OSSI=1` driving all four TIM outputs LOW when `MOE=0`, all
  MOSFETs are OFF in IDLE/FAULT/BOOT — safe at boot, stop, and fault.

### Build-guide v3.1 cross-reference — parameters that match
Verified item-by-item against the official build guide:
- DC sensor divider 100 kΩ / 5.1 kΩ with 5 V reference → `CONFIG_VDC_DIVIDER_GAIN`,
  `CONFIG_VDC_ADC_REF` ([config.h](Core/Inc/config.h)). Resolution 0.252 V/count.
- ACS712 sensor: 100 mV/A, 2.5 V zero, 0.6 divider, 3.3 V ref → all four
  `CONFIG_ACS_*` and `CONFIG_CUR_ADC_REF` constants match exactly.
- Protection thresholds: UV<40 V, OV>58 V, OC>15 A, IMBAL>10 V — match
  guide section 5.1 byte-for-byte.
- Bootstrap precharge 5–10 ms → firmware uses 6 ms full-LS-on (functionally
  equivalent to guide's "50% duty for 5–10 ms" suggestion; both leave the
  bootstrap cap fully charged).
- SPI ≤ 1 MHz with 6N137 round-trip margin → bit-bang runs at ~140 kHz,
  well under the guide's 2 MHz hard limit.
- Pin header signals (header pins 9–18: SCK, three CS, three MISO, FAULT_OUT,
  +5 V, +3.3 V, GND, GND) — all match firmware GPIO usage.

### Build-guide v3.1 cross-reference — documentation errors found in the guide
These are guide-side errors; the firmware is correct. Flagged here so the
team can publish a v3.2 errata.
- **PWM_1L pin (header pin 4).** Guide lists "PA10 (TIM1_CH2N)". PA10 has
  no TIM1_CH2N alternate function on the STM32F303RE. The only valid
  TIM1_CH2N pins on this package are PA12, PB0, and PB14. Firmware uses
  **PA12 (AF6)** — confirmed by user as the actual board wiring.
- **TIM8 channel pins (header pins 5–8).** Guide lists PC6/PC7/PC8/PC9 as
  TIM8_CH1/CH1N/CH2/CH2N. On F303RE, PC6 = TIM8_CH1 ✓ but PC7 = TIM8_CH2
  (not CH1N), PC8 = TIM8_CH3 (not CH2), PC9 = TIM8_CH4 (not CH2N). Firmware
  uses **PB6/PB3/PB8/PB0** which do map correctly to TIM8 CH1/CH1N/CH2/CH2N
  — confirmed by user as the actual board wiring.

### Build-guide v3.1 cross-reference — deliberate firmware deviations from guide
- **Modulation strategy.** Guide section 1.2 specifies "In-Phase Disposition
  Level-Shifted PWM (IPD LS-PWM)". Firmware currently runs a 500 Hz
  quantize-to-5-levels staircase, which is neither IPD nor PSC and matches
  the guide only in producing a 5-level output. The upcoming rebalance
  branch will replace this with **PSC-PWM (phase-shifted carriers, unipolar
  per cell, 90° shift between the two bridges)** rather than IPD. Reason:
  PSC is naturally bridge-balanced, whereas IPD has an inherent bridge-loss
  asymmetry that needs an additional bridge-swap each fundamental cycle to
  even out. The user has accepted this deviation and will publish a guide
  v3.2 erratum.
- **Switching frequency.** Guide specifies 5 kHz; current firmware runs at
  500 Hz. Will be raised to 5 kHz in the PSC-PWM branch.
- **Protection scan rate.** Guide implies ≥20 kHz ("4+ scans per 5 kHz
  period"); firmware uses 1 kHz. Raising this requires speeding up the
  bit-bang SPI (currently ~140 kHz, can go to ~1 MHz). Deferred pending
  the switching-frequency change above.
- **Dead-time.** Guide specifies 500 ns – 1 µs; firmware uses 2 µs (more
  conservative). Bench-validated, left as-is.
- **System clock.** Guide example uses 72 MHz (needs external HSE crystal);
  firmware uses 64 MHz from HSI. All PWM and timer arithmetic is derived
  from the actual clock, so the numbers stay self-consistent.

### Decisions
- **MCP3201 bit-shift trusts the build guide over my datasheet reading.**
  Two readings of the MCP3201 timing are defensible: (a) NULL bit appears
  at the 1st SCK rising edge sample → shift `>> 3` (guide); (b) NULL appears
  at the 3rd SCK rising edge sample after the documented 1.5 SCK sample
  window → shift `>> 1` (my earlier analysis). Both depend on how
  aggressively the device drives DOUT after CS↓. Without bench evidence
  to break the tie, defer to the team's documented design and keep
  `>> 3`. Bringup verification step added in code comment.
- **PSC-PWM chosen over the guide's IPD LS-PWM** for the upcoming
  rebalance branch. The user's reported bridge-1 thermal/current imbalance
  is exactly the failure mode IPD induces (one bridge always handles the
  inner band, the other the outer band). PSC fixes this naturally without
  the cycle-by-cycle bridge-swap that IPD would need. Trade-off: deviation
  from the documented design — a v3.2 guide erratum will be issued.
- **95% duty clamp accepted as a guide-compliance change**, even though
  it touches PWM. The clamp is a parameter, not a modulation-algorithm
  change, and is required by the guide for bootstrap safety.
- **Protection filter strategy: N-of-M consecutive, not IIR-on-protection.**
  Three options were on the table — single-sample raw (status quo, prone
  to nuisance trips), IIR-filtered values (smooth but adds ~20–30 ms lag
  and could miss a short overcurrent spike), and N-of-M consecutive
  (rejects single-sample noise while keeping fast trip on a sustained
  event). Picked N-of-M because the protection path needs to be fast
  *and* immune to glitches.
- **`RESCAN` allowed in IDLE and FAULT, not just IDLE.** Allowing it in
  FAULT means a sensor that disappeared can be recovered without first
  having to clear the latched fault (which would itself be blocked by
  `FAULT_SENSOR_LOST` being active). Blocked in PRECHARGE/RUN because
  `Sensing_SelfTest` performs blocking SPI reads that should not race
  with the sense loop.
- **Status and telemetry use `available`, not `initialized`.** Both lines
  should reflect *current* reality, not history. A lost sensor reads
  `NAN` everywhere; this matches operator expectation.
- **HAL cleanup deferred.** The Drivers/ tree (~10–15 KB of dead Flash)
  and the `extern TIM_HandleTypeDef htim1` stub in `stm32f3xx_it.c` were
  left in place to keep the diff focused on bringup-blocking issues. The
  only HAL call that actually runs is `HAL_IncTick()` from SysTick, which
  just increments an unused `uwTick`. Cleanup is a future task once the
  board is up.
- **PWM generation untouched.** The bridge-level quantization in
  `PWM_Update_IRQHandler` ([main.c:285-366](Core/Src/main.c#L285-L366))
  always uses bridge 1 for the ±1 step, leaving bridge 2 freewheeling.
  This produces unequal switching loss between bridges (confirmed in
  hardware: one of bridge 1's MOSFETs runs hotter, and bridge 1 carries
  more current than bridge 2). The fix is tracked as [#known-issue-1](#known-issues)
  and will be done in a dedicated branch — it touches the modulator
  itself and deserves separate attention.

### Known issues
- **Bridge 1 thermal/current imbalance** (concern #8 from the review).
  See "Decisions" above and the [README](README.md). Will be addressed
  in a separate branch.
- **Lost sensors only recover via `RESCAN` or reboot.** No automatic
  re-arm. Intentional: a sensor that flickered out once probably has a
  wiring issue that should be diagnosed before trusting it again.
- **Protection uses single-sample raw ADC counts**, now wrapped in a
  3-sample debounce. Still no per-channel IIR for the protection path
  (telemetry has IIR with `alpha=0.1`, but protection reads `last_raw`).
  If hardware bringup reveals slow drift faults that the debounce misses,
  consider adding a slow-drift filter alongside.

---

## [0.3.0] — 2026-05-15 — Dashboard added

Commit `7402281`. PC-side companion app for visualization, sim-only fault
playback, and live serial control.

### Added
- `dashboard/` Python application built on PySide6 + pyqtgraph + pyserial.
  - `protocol.py` — NMEA-style line parser, matches firmware checksums.
  - `models.py` — `TelemetryFrame` dataclass, mode/fault enum mirrors.
  - `sim.py` — `SimController` with deterministic step()-based timeline
    and 8 pre-baked scenario presets.
  - `sources.py` — `BaseSource` / `SimSource` / `SerialSource` /
    `ReplaySource` adapters. All emit the same `frame_received` signal.
  - `widgets.py` — FSM strip, fault badge, modulation/output twin, sensor
    gauges.
  - `app.py` — main window, command panel, scenario presets, log pane.
- `dashboard/tests/test_protocol.py` and `test_sim.py` — unit tests that
  do **not** require PySide6 to run, so CI can verify parser + sim logic.

### Decisions
- **Sim and serial sources are fully separate.** Scenario buttons are
  disabled when "Arm live START" is checked; scenarios always play
  against the simulator. The simulator never injects fake sensor values
  into the firmware. This was deliberate — a fault-demo button that
  accidentally trips a real power stage is exactly the kind of footgun
  that defeats the purpose of having a dashboard.
- **"Arm live START" guard.** Live `START` is blocked behind a checkbox
  the operator has to flip explicitly. Other commands (`STOP`, `STATUS`,
  `MODE`, `MI`, `CLEAR`) are not gated.
- **Frames carry a `source` field.** `_handle_frame` filters by source
  so simulator frames don't pollute the live serial view and vice versa
  when the user switches sources mid-session.
- **PySide6 + pyqtgraph instead of matplotlib.** pyqtgraph integrates
  with Qt's event loop and stays smooth at 20 Hz telemetry without the
  matplotlib backend redraws stuttering. Tests intentionally don't import
  Qt so they run in a headless environment.
- **Telemetry parser is forgiving.** Lines with a bad checksum still
  produce a `TelemetryFrame` (marked `checksum_valid=False`) instead of
  being dropped, so operators can still see *something* during bringup
  if a wire is noisy.

---

## [0.2.0] — 2026-05-13 — FSM, sensing, protection, UART (`fsm: Initial commit`)

Commit `0198b96`. The bulk of the firmware. Brings the project from a
PWM-only CubeMX skeleton to a complete supervisory firmware with sensing,
protection, mode management, and UART control. ~1745 lines added.

### Added
- **FSM** ([fsm.c](Core/Src/fsm.c)): `BOOT → IDLE → PRECHARGE → RUN → FAULT`.
  Boot runs an ADC self-test, selects the best sensing mode, and drops
  to IDLE. START enables MOE and arms a bootstrap precharge; the PWM ISR
  forces low-sides ON for 3 PWM periods (6 ms at 500 Hz). When
  `g_precharge_done` is set, the main loop transitions to RUN. STOP and
  fault entry both drop MOE and reset precharge state.
- **MCP3201 bit-banged SPI** ([spi_mcp3201.c](Core/Src/spi_mcp3201.c)):
  One shared SCK on PA5, three independent MISOs on PA6/PC3/PC4, three
  CS lines on PC0/PC1/PC2. Reads all selected channels in parallel
  during a single SCK sweep.
- **Sensing layer** ([sensing.c](Core/Src/sensing.c)): TIM6 at 1 kHz
  sets `g_sense_pending`; main loop calls `Sensing_Service` to do the
  blocking SPI read. Per-channel IIR with `alpha=0.1` for telemetry,
  rail-stuck detector that demotes a channel to "unavailable" after 5
  consecutive `0x000` or `0xFFF` reads.
- **Protection** ([protection.c](Core/Src/protection.c)): UV/OV/OC/IMBAL
  thresholds (40/58/15/10), per-mode protection set, latched faults that
  require `CLEAR` after the underlying condition is gone.
- **Six sensing modes** with graceful boot-time degradation: `FULL`,
  `DC_ONLY`, `CUR_ONLY`, `OPEN`, `DC1`, `DC2`. Boot picks the most
  capable mode that the available sensors support.
- **UART telemetry + command** ([uart_telem.c](Core/Src/uart_telem.c)):
  USART2 @ 115200 8N1, line-based commands (`START`/`STOP`/`CLEAR`/`MODE
  <0..5>`/`STATUS`/`HELP`/`MI <x>`), NMEA-style telemetry at 20 Hz with
  XOR checksums, `$A`/`$E`/`$F`/`$H`/`$S`/`$T` line prefixes.
- **FSM_NOTES.md** with the state diagram and per-mode protection table.

### Changed
- `main.c` clock init refactored to enable HSI→PLL→64 MHz without
  external crystal. SysTick configured to 1 kHz for `FSM_Millis()`.
  System init order rearranged so all peripherals are up before
  `FSM_Init()` runs the self-test.
- `stm32f3xx_it.c` wired SysTick → `FSM_SysTickISR`, TIM1_UP →
  `PWM_Update_IRQHandler`, TIM6_DAC → `Sensing_TIM6_IRQHandler`, USART2
  → `UART_USART2_IRQHandler`. HAL stub vectors remain for any unused
  IRQs.
- README expanded to document pinout, sensing modes, command and
  telemetry protocol, bringup notes, and safety warnings.

### Decisions
- **Bare-metal CMSIS, not HAL.** All new peripheral code uses direct
  register writes (`RCC->`, `TIM1->`, etc.). HAL files are still
  compiled in but only `HAL_IncTick()` actually runs (from SysTick). The
  reason: deterministic, transparent timing for the PWM ISR — HAL adds
  layers of indirection that are awkward to reason about for a hard
  real-time control loop.
- **Bit-banged SPI for MCP3201 instead of hardware SPI1.** The isolated
  6N137 optocouplers on the three MISO lines don't tri-state cleanly, so
  the three MISOs can't share a bus. Bit-banging clocks all three with
  one SCK and reads three GPIO inputs in parallel. Hardware SPI1 was
  not used because it only supports one MISO.
- **Independent 6N137 isolation per MISO line.** Documented in the README
  as the reason MISOs aren't bussed. Trade-off: more parts, but cleaner
  signals.
- **TIM6 ISR sets a flag; main loop does the SPI read.** Keeps the ISR
  short (~10 cycles) and isolates the bit-bang timing from interrupt
  context where higher-priority IRQs can stretch it. SPI bit period
  becomes ~3 µs (well under the MCP3201's 1.6 MHz max) but absolute
  timing isn't critical — only edge ordering matters.
- **Protection uses `last_raw`, not `filtered_value`.** Fast trip wins
  over smooth display. Telemetry/STATUS use the filtered value.
  (Pre-existing nuisance-trip risk addressed in the 2026-05-16 fixes
  via N-of-M debounce.)
- **`OPEN` mode is allowed but warns.** Boot and `MODE` selection both
  emit `WARNING_OPEN_LOOP_NO_PROTECTION`. Intended for demos where the
  sensor wiring isn't done yet; disables all protection.
- **Lost sensors don't auto-recover.** Once `available=0`, the channel
  is dropped from the scan mask and stays dropped until reboot. The
  RESCAN command added in 2026-05-16 gives an explicit recovery path.
- **IRQ priorities: TIM1=0, TIM6=2, USART2=3, SysTick=15.** TIM1 update
  is highest because PWM CCR updates must not be late. TIM6 is short and
  just sets a flag. USART is one byte at a time at 87 µs intervals.
  SysTick only increments a counter — lowest priority is fine.
- **Telemetry at 20 Hz.** Comfortably below the UART's 115200-baud
  capacity (~80 bytes per 50 ms ≈ 16 kbps), leaves headroom for command
  echoes and async error/fault messages.
- **NMEA-style line protocol with XOR checksum.** Easy to parse in any
  language, human-readable on a terminal, robust against half-typed
  commands during interactive bringup.
- **5-level CHB modulation by quantization, not phase-shifted carriers.**
  The PWM ISR quantizes the sine reference into {−2, −1, 0, +1, +2} via
  hard thresholds and routes each level to a fixed bridge state. Bridge 1
  is *always* the one carrying the ±1 step. (This is the source of the
  thermal imbalance noted in 2026-05-16.)
- **500 Hz PWM, 256-sample sine LUT at 50 Hz fundamental.** Phase
  increment = (50/500) × 256 = 25.6 samples/ISR. PWM period 2 ms,
  fundamental period 20 ms.
- **2 µs dead-time via BDTR.DTG = 0x80 at 64 MHz.** Matches typical
  power MOSFET turn-off times with margin.
- **6 ms bootstrap precharge (3 PWM periods).** Long enough to charge
  100 nF bootstrap caps through typical 100 Ω–1 kΩ paths many times over.
- **`OSSR=1` and `OSSI=1` in BDTR.** Outputs are forced to their inactive
  level (LOW, with default polarity) whenever any of CCxE/CCxNE is 0 or
  MOE is 0. Combined with the TLP250 non-inverting topology, this means
  every state where the firmware *thinks* the bridge is off actually
  drives all MOSFETs off. Confirmed safe (see 2026-05-16 entry).
- **DC sensor scale: `105.1 / 5.1` divider, 5.0 V ADC reference.**
  Full-scale ≈ 103 V. With 40/58 V protection limits, the DC bus is
  expected to sit around 50 V per bridge.
- **Current sensor: 0.1 V/A sensitivity, 2.5 V zero, 0.6 divider, 3.3 V
  ADC reference.** Implies a Hall-effect transducer with a passive
  divider into the MCP3201's input range. Exact part number is in the
  hardware schematic, not in firmware.

---

## [0.1.0] — 2026-05-12 — Project skeleton + README (`Initial commit`, `Add README`)

Commits `4ac72e7` and `453fc1b`.

### Added
- STM32CubeIDE project for STM32F303RETx (Nucleo-F303RE), 64-pin LQFP.
- CubeMX-generated HAL skeleton: `Drivers/STM32F3xx_HAL_Driver`,
  `Drivers/CMSIS`, `Core/Src/main.c` (PWM-only), `Core/Src/syscalls.c`,
  `Core/Src/sysmem.c`, `Core/Src/stm32f3xx_hal_msp.c`,
  `Core/Startup/startup_stm32f303retx.s`, `STM32F303RETX_FLASH.ld`.
- Initial `main.c` with TIM1 + TIM8 complementary PWM generating the
  5-level cascaded H-bridge output. Verified on the bench at this stage
  — this is the "old PWM" that subsequent commits preserve unchanged.
- Top-level README placeholder.

### Decisions
- **STM32F303RE on the Nucleo-64.** Chosen for: dual advanced-control
  timers (TIM1 + TIM8) with complementary outputs and configurable
  dead-time, hardware FPU, on-board ST-LINK for both flashing and the
  VCP used by the UART protocol.
- **TIM1 = bridge 1, TIM8 = bridge 2.** Each timer drives two
  complementary leg pairs (CH1/CH1N + CH2/CH2N), giving the four
  half-bridge gate signals per H-bridge.
- **No external crystal.** HSI/2 × PLL = 64 MHz. Saves the crystal BOM
  and avoids the unsupported-PLL-macro paths in older CMSIS headers.

---

## Known Issues (active)

1. **Bridge-1 thermal/current imbalance.** Bridge 1 always carries the
   ±1 step in 5-level mode; bridge 2 only switches for the ±2 levels.
   Bench observation: one of bridge 1's MOSFETs runs hot, and bridge 1
   carries more current than bridge 2. Will be addressed in a dedicated
   branch — either a quick rebalance (alternate which bridge handles
   ±1 each fundamental cycle) or a full PSC-PWM rewrite with
   phase-shifted carriers.
2. **HAL is compiled but unused.** ~10–15 KB of dead Flash and a stray
   `extern TIM_HandleTypeDef htim1` in `stm32f3xx_it.c`. Cleanup
   deferred until after first hardware bringup.
3. **`delay_half_period` is slower than the comment implies.** Volatile
   loop overhead pushes SCK to ~140 kHz instead of the documented "below
   1 MHz" target. Doesn't matter functionally (MCP3201 doesn't care)
   but worth replacing with a DWT cycle counter if precise timing is
   ever needed.
4. **PA5 doubles as Nucleo's LD2 LED.** It flickers dimly during every
   ADC scan. Cosmetic only.

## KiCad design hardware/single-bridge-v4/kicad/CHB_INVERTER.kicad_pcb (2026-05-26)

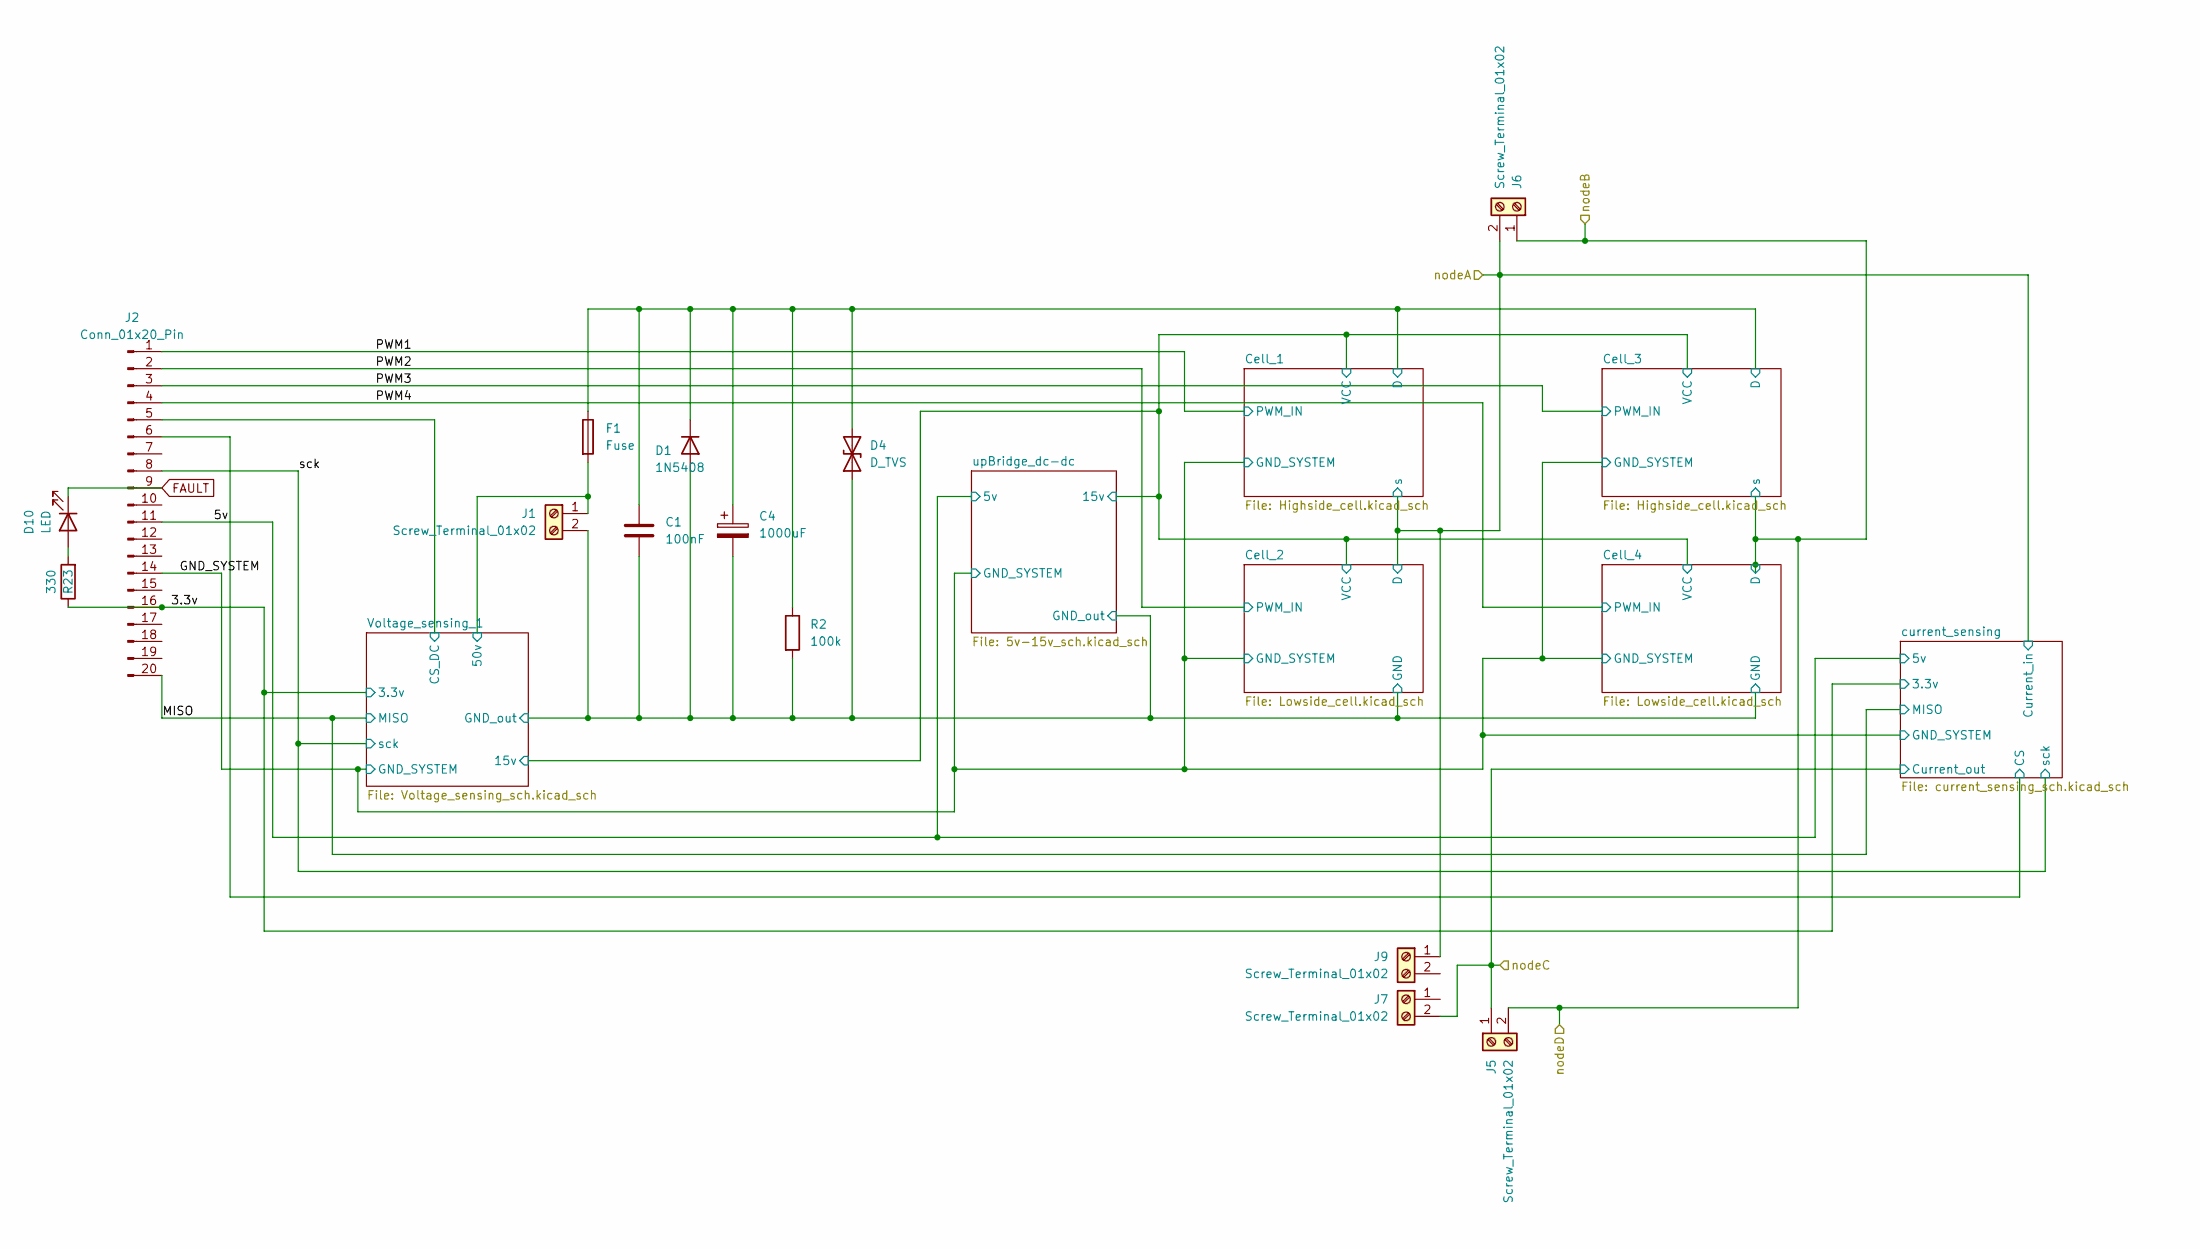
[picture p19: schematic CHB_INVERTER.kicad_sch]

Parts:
C1: 100nF; C_Disc_D5.0mm_W2.5mm_P5.00mm
C4: 1000uF; CP_Radial_D18.0mm_P7.50mm
D1: 1N5408; D_DO-201AD_P15.24mm_Horizontal
D4: D_TVS; D_DO-201AD_P15.24mm_Horizontal
D10: LED; LED_D5.0mm
F1: Fuse; Fuseholder_Cylinder-5x20mm_Schurter_0031_8201_Horizontal_Op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
J1, J5, J6, J7, J9: Screw_Terminal_01x02; TerminalBlock_Phoenix_MKDS-1,5-2-5.08_1x02_P5.08mm_Horizont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
J2: Conn_01x20_Pin; PinHeader_1x20_P2.54mm_Vertical
R2: 100k; R_Axial_DIN0617_L17.0mm_D6.0mm_P20.32mm_Horizontal
R23: 330; R_Axial_DIN0207_L6.3mm_D2.5mm_P10.16mm_Horizontal

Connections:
/3.3v: J2.16, R23.1; also elsewhere on the board
/5v: J2.11; also elsewhere on the board
/Cell_1/D: C1.1, C4.1, D1.1 (K), D4.2 (A2), F1.1, R2.1; also elsewhere on the board
/Cell_2/GND: C1.2, C4.2, D1.2 (A), D4.1 (A1), J1.2, R2.2; also elsewhere on the board
/GND_SYSTEM: J2.14; also elsewhere on the board
/MISO: J2.20; also elsewhere on the board
/PWM1: J2.1; also elsewhere on the board
/PWM2: J2.2; also elsewhere on the board
/PWM3: J2.3; also elsewhere on the board
/PWM4: J2.4; also elsewhere on the board
/Voltage_sensing_1/50v: F1.2, J1.1; also elsewhere on the board
/Voltage_sensing_1/CS_DC: J2.5; also elsewhere on the board
/current_sensing/CS: J2.6; also elsewhere on the board
/nodeA: J6.2, J9.1; also elsewhere on the board
/nodeB: J5.2, J6.1; also elsewhere on the board
/nodeC: J5.1, J7.2; also elsewhere on the board
/sck: J2.8; also elsewhere on the board
FAULT: D10.1 (K), J2.9
unnamed: D10.2 (A), R23.2

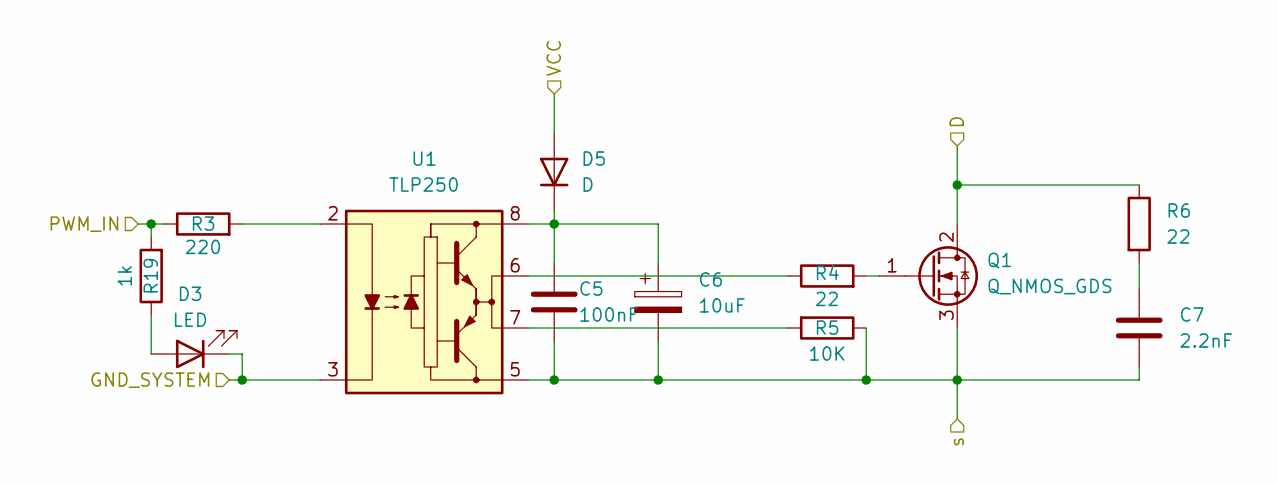
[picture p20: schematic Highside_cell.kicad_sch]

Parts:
C5: 100nF; C_Disc_D5.0mm_W2.5mm_P5.00mm
C6: 10uF; CP_Radial_D5.0mm_P2.50mm
C7: 2.2nF; C_Rect_L7.2mm_W2.5mm_P5.00mm_FKS2_FKP2_MKS2_MKP2
D3: LED; LED_D5.0mm
D5: D; D_DO-41_SOD81_P10.16mm_Horizontal
Q1: Q_NMOS_GDS; TO-220-3_Vertical
R3: 220; R_Axial_DIN0207_L6.3mm_D2.5mm_P10.16mm_Horizontal
R4: 22; R_Axial_DIN0207_L6.3mm_D2.5mm_P10.16mm_Horizontal
R5: 10K; R_Axial_DIN0207_L6.3mm_D2.5mm_P10.16mm_Horizontal
R6: 22; R_Axial_DIN0617_L17.0mm_D6.0mm_P20.32mm_Horizontal
R19: 1k; R_Axial_DIN0207_L6.3mm_D2.5mm_P10.16mm_Horizontal
U1: TLP250; DIP-8_W7.62mm

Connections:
/Cell_1/D: Q1.2 (D), R6.1; also elsewhere on the board
/Cell_1/VCC: D5.2 (A); also elsewhere on the board
/GND_SYSTEM: D3.1 (K), U1.3 (C); also elsewhere on the board
/PWM1: R3.1, R19.2; also elsewhere on the board
/nodeA: C5.2, C6.2, C7.2, Q1.3 (S), R5.1, U1.5 (VEE); also elsewhere on the board
unnamed: C7.1, R6.2
unnamed: D3.2 (A), R19.1
unnamed: C5.1, C6.1, D5.1 (K), U1.8 (VCC)
unnamed: Q1.1 (G), R4.2
unnamed: R4.1, U1.6 (VO)
unnamed: R5.2, U1.7 (VO)
unnamed: R3.2, U1.2 (A)

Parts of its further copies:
C10: 100nF; C_Disc_D5.0mm_W2.5mm_P5.00mm
C11: 10uF; CP_Radial_D5.0mm_P2.50mm
C12: 2.2nF; C_Rect_L7.2mm_W2.5mm_P5.00mm_FKS2_FKP2_MKS2_MKP2
D6: D; D_DO-41_SOD81_P10.16mm_Horizontal
D7: LED; LED_D5.0mm
Q3: Q_NMOS_GDS; TO-220-3_Vertical
R11: 220; R_Axial_DIN0207_L6.3mm_D2.5mm_P10.16mm_Horizontal
R12: 22; R_Axial_DIN0207_L6.3mm_D2.5mm_P10.16mm_Horizontal
R13: 10K; R_Axial_DIN0207_L6.3mm_D2.5mm_P10.16mm_Horizontal
R14: 22; R_Axial_DIN0617_L17.0mm_D6.0mm_P20.32mm_Horizontal
R20: 1k; R_Axial_DIN0207_L6.3mm_D2.5mm_P10.16mm_Horizontal
U3: TLP250; DIP-8_W7.62mm

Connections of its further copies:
/Cell_1/D: Q3.2 (D), R14.1; also elsewhere on the board
/Cell_1/VCC: D6.2 (A); also elsewhere on the board
/GND_SYSTEM: D7.1 (K), U3.3 (C); also elsewhere on the board
/PWM3: R11.1, R20.2; also elsewhere on the board
/nodeB: C10.2, C11.2, C12.2, Q3.3 (S), R13.1, U3.5 (VEE); also elsewhere on the board
unnamed: C12.1, R14.2
unnamed: C10.1, C11.1, D6.1 (K), U3.8 (VCC)
unnamed: D7.2 (A), R20.1
unnamed: Q3.1 (G), R12.2
unnamed: R12.1, U3.6 (VO)
unnamed: R13.2, U3.7 (VO)
unnamed: R11.2, U3.2 (A)

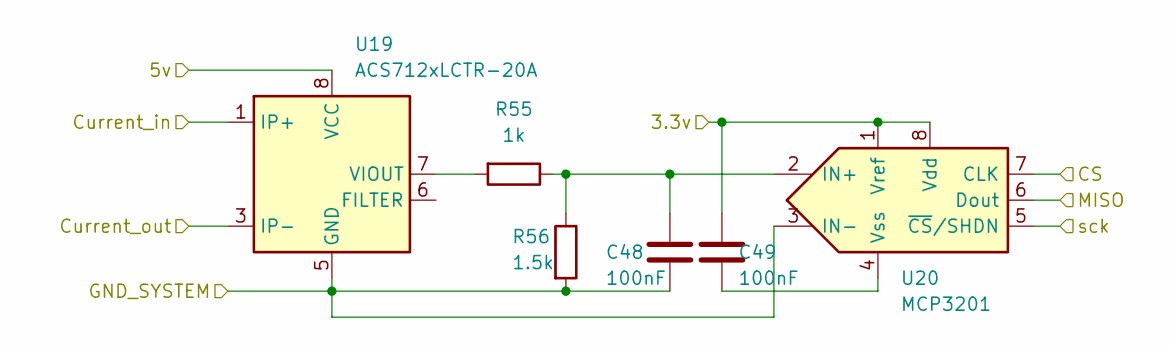
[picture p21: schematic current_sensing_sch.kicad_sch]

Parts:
C48, C49: 100nF; C_Disc_D5.0mm_W2.5mm_P5.00mm
R55: 1k; R_Axial_DIN0207_L6.3mm_D2.5mm_P10.16mm_Horizontal
R56: 1.5k; R_Axial_DIN0207_L6.3mm_D2.5mm_P10.16mm_Horizontal
U19: ACS712xLCTR-20A; SOIC-8_3.9x4.9mm_P1.27mm
U20: MCP3201; DIP-8_W7.62mm

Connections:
/3.3v: C49.1, U20.1 (Vref), U20.8 (Vdd); also elsewhere on the board
/5v: U19.8 (VCC); also elsewhere on the board
/GND_SYSTEM: C48.2, R56.2, U19.5 (GND), U20.3 (IN-); also elsewhere on the board
/MISO: U20.6 (Dout); also elsewhere on the board
/current_sensing/CS: U20.7 (CLK); also elsewhere on the board
/nodeA: U19.1 (IP+), U19.2 (IP+); also elsewhere on the board
/nodeC: U19.3 (IP-), U19.4 (IP-); also elsewhere on the board
/sck: U20.5 (~CS/SHDN); also elsewhere on the board
unnamed: R55.2, U19.7 (VIOUT)
unnamed: C48.1, R55.1, R56.1, U20.2 (IN+)
unnamed: C49.2, U20.4 (Vss)

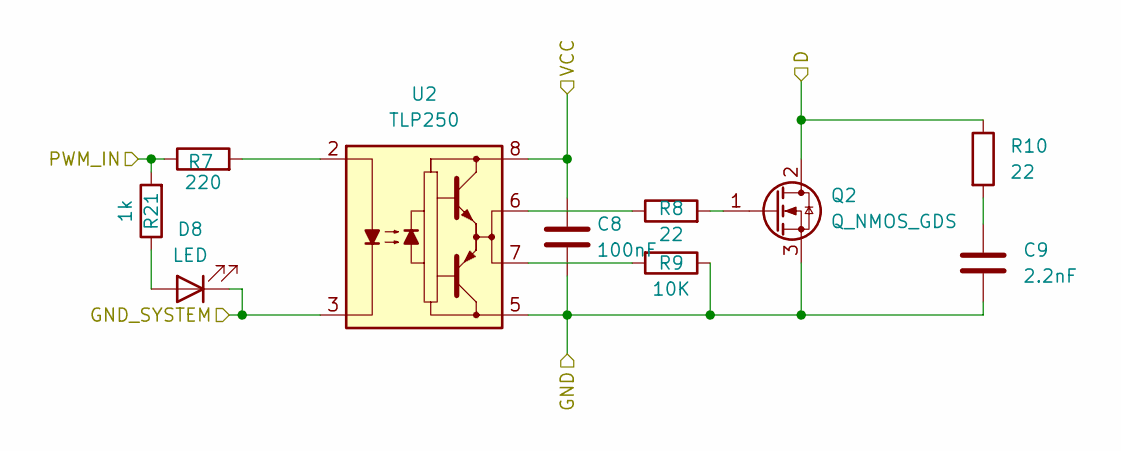
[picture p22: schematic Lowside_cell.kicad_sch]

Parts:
C8: 100nF; C_Disc_D5.0mm_W2.5mm_P5.00mm
C9: 2.2nF; C_Rect_L7.2mm_W2.5mm_P5.00mm_FKS2_FKP2_MKS2_MKP2
D8: LED; LED_D5.0mm
Q2: Q_NMOS_GDS; TO-220-3_Vertical
R7: 220; R_Axial_DIN0207_L6.3mm_D2.5mm_P10.16mm_Horizontal
R8: 22; R_Axial_DIN0207_L6.3mm_D2.5mm_P10.16mm_Horizontal
R9: 10K; R_Axial_DIN0207_L6.3mm_D2.5mm_P10.16mm_Horizontal
R10: 22; R_Axial_DIN0617_L17.0mm_D6.0mm_P20.32mm_Horizontal
R21: 1k; R_Axial_DIN0207_L6.3mm_D2.5mm_P10.16mm_Horizontal
U2: TLP250; DIP-8_W7.62mm

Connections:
/Cell_1/VCC: C8.1, U2.8 (VCC); also elsewhere on the board
/Cell_2/GND: C8.2, C9.2, Q2.3 (S), R9.1, U2.5 (VEE); also elsewhere on the board
/GND_SYSTEM: D8.1 (K), U2.3 (C); also elsewhere on the board
/PWM2: R7.1, R21.2; also elsewhere on the board
/nodeA: Q2.2 (D), R10.1; also elsewhere on the board
unnamed: C9.1, R10.2
unnamed: D8.2 (A), R21.1
unnamed: Q2.1 (G), R8.2
unnamed: R8.1, U2.6 (VO)
unnamed: R9.2, U2.7 (VO)
unnamed: R7.2, U2.2 (A)

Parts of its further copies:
C13: 100nF; C_Disc_D5.0mm_W2.5mm_P5.00mm
C14: 2.2nF; C_Rect_L7.2mm_W2.5mm_P5.00mm_FKS2_FKP2_MKS2_MKP2
D9: LED; LED_D5.0mm
Q4: Q_NMOS_GDS; TO-220-3_Vertical
R15: 220; R_Axial_DIN0207_L6.3mm_D2.5mm_P10.16mm_Horizontal
R16: 22; R_Axial_DIN0207_L6.3mm_D2.5mm_P10.16mm_Horizontal
R17: 10K; R_Axial_DIN0207_L6.3mm_D2.5mm_P10.16mm_Horizontal
R18: 22; R_Axial_DIN0617_L17.0mm_D6.0mm_P20.32mm_Horizontal
R22: 1k; R_Axial_DIN0207_L6.3mm_D2.5mm_P10.16mm_Horizontal
U4: TLP250; DIP-8_W7.62mm

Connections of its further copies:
/Cell_1/VCC: C13.1, U4.8 (VCC); also elsewhere on the board
/Cell_2/GND: C13.2, C14.2, Q4.3 (S), R17.1, U4.5 (VEE); also elsewhere on the board
/GND_SYSTEM: D9.1 (K), U4.3 (C); also elsewhere on the board
/PWM4: R15.1, R22.2; also elsewhere on the board
/nodeB: Q4.2 (D), R18.1; also elsewhere on the board
unnamed: C14.1, R18.2
unnamed: D9.2 (A), R22.1
unnamed: Q4.1 (G), R16.2
unnamed: R16.1, U4.6 (VO)
unnamed: R17.2, U4.7 (VO)
unnamed: R15.2, U4.2 (A)

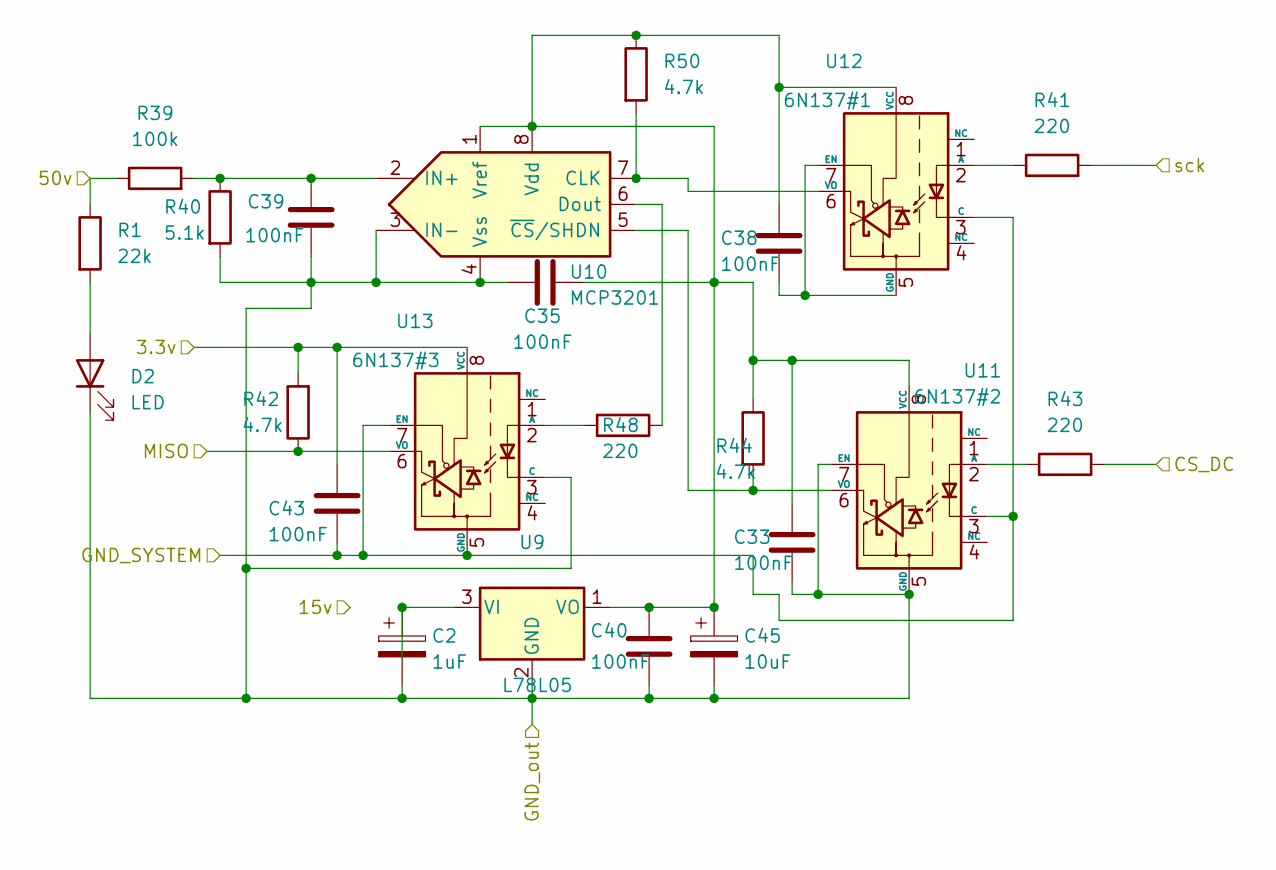
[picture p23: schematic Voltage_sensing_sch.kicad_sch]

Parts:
C2: 1uF; CP_Radial_D4.0mm_P1.50mm
C33, C35, C38, C39, C40, C43: 100nF; C_Disc_D5.0mm_W2.5mm_P5.00mm
C45: 10uF; CP_Radial_D5.0mm_P2.50mm
D2: LED; LED_D3.0mm
R1: 22k; R_Axial_DIN0207_L6.3mm_D2.5mm_P10.16mm_Horizontal
R39: 100k; R_Axial_DIN0207_L6.3mm_D2.5mm_P10.16mm_Horizontal
R40: 5.1k; R_Axial_DIN0207_L6.3mm_D2.5mm_P10.16mm_Horizontal
R41, R43, R48: 220; R_Axial_DIN0207_L6.3mm_D2.5mm_P10.16mm_Horizontal
R42, R44, R50: 4.7k; R_Axial_DIN0207_L6.3mm_D2.5mm_P10.16mm_Horizontal
U9: L78L05; TO-92_Inline
U10: MCP3201; DIP-8_W7.62mm
U11: 6N137#2; DIP-8_W7.62mm
U12: 6N137#1; DIP-8_W7.62mm
U13: 6N137#3; DIP-8_W7.62mm

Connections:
/3.3v: C43.1, R42.2, U13.8 (VCC); also elsewhere on the board
/Cell_2/GND: C2.2, C33.2, C35.1, C39.2, C40.2, C45.2, D2.1 (K), R40.2, U9.2 (GND), U10.3 (IN-), U10.4 (Vss), U11.5 (GND), U11.7 (EN), U13.3 (C); also elsewhere on the board
/GND_SYSTEM: C43.2, U11.3 (C), U12.3 (C), U13.5 (GND), U13.7 (EN); also elsewhere on the board
/MISO: R42.1, U13.6 (VO); also elsewhere on the board
/Voltage_sensing_1/50v: R1.1, R39.1; also elsewhere on the board
/Voltage_sensing_1/CS_DC: R43.1; also elsewhere on the board
/sck: R41.2; also elsewhere on the board
unnamed: D2.2 (A), R1.2
unnamed: C2.1, U9.3 (VI)
unnamed: R50.2, U10.7 (CLK), U12.6 (VO)
unnamed: R48.1, U10.6 (Dout)
unnamed: C39.1, R39.2, R40.1, U10.2 (IN+)
unnamed: C33.1, C35.2, C38.1, C40.1, C45.1, R44.1, R50.1, U9.1 (VO), U10.1 (Vref), U10.8 (Vdd), U11.8 (VCC), U12.8 (VCC)
unnamed: R44.2, U10.5 (~CS/SHDN), U11.6 (VO)
unnamed: R43.2, U11.2 (A)
unnamed: R41.1, U12.2 (A)
unnamed: C38.2, U12.5 (GND), U12.7 (EN)
unnamed: R48.2, U13.2 (A)

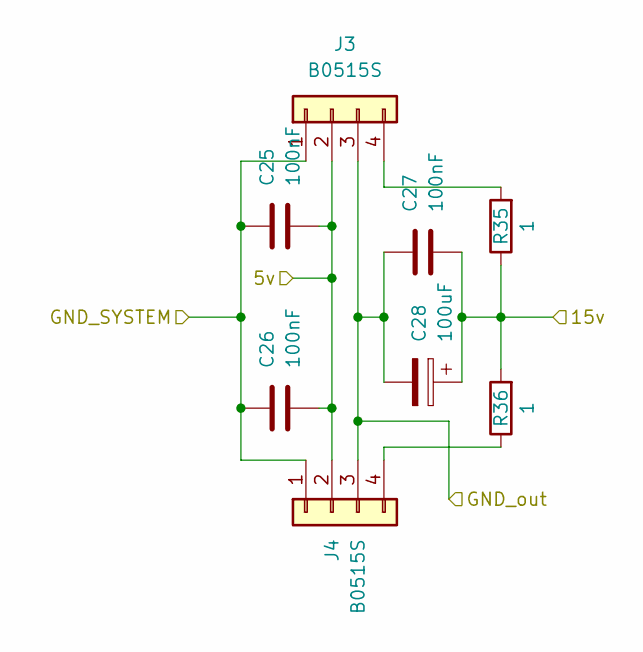
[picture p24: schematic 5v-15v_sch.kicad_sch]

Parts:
C25, C26, C27: 100nF; C_Disc_D5.0mm_W2.5mm_P5.00mm
C28: 100uF; CP_Radial_D6.3mm_P2.50mm
J3, J4: B0515S; my_B0515S
R35, R36: 1; R_Axial_DIN0207_L6.3mm_D2.5mm_P10.16mm_Horizontal

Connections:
/5v: C25.2, C26.2, J3.2, J4.2; also elsewhere on the board
/Cell_1/VCC: C27.2, C28.1, R35.1, R36.2; also elsewhere on the board
/Cell_2/GND: C27.1, C28.2, J3.3, J4.3; also elsewhere on the board
/GND_SYSTEM: C25.1, C26.1, J3.1, J4.1; also elsewhere on the board
unnamed: J3.4, R35.2
unnamed: J4.4, R36.1

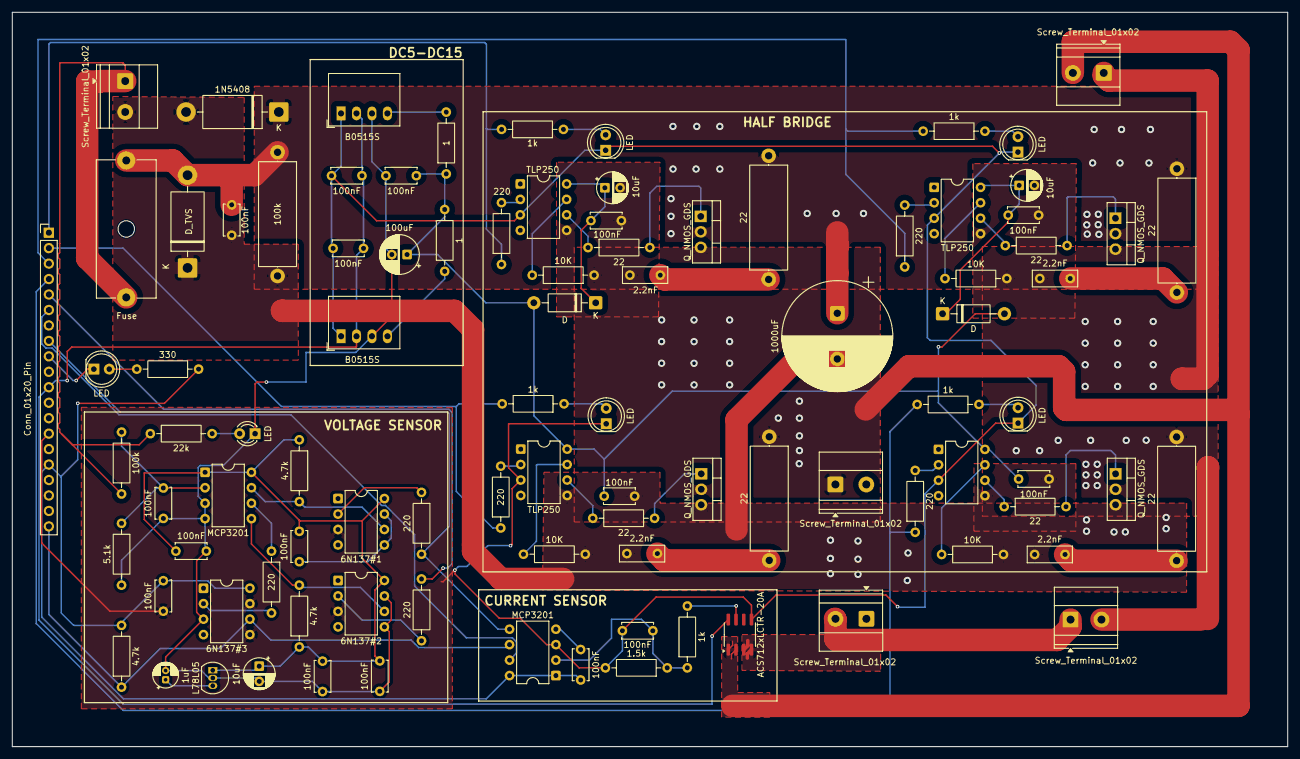
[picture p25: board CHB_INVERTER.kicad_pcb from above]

Board: 2 copper layers, 209.6 x 120.7 mm, 95 parts (0 on the bottom side), 62 nets.

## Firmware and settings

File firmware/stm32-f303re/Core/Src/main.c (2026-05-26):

#include "stm32f3xx.h"
#include "fsm.h"
#include "pwm_modulator.h"
#include "sensing.h"
#include "spi_mcp3201.h"
#include "uart_telem.h"
#include <stdint.h>

#define TIMER_CLK_HZ 64000000u

static void SystemClock_Config(void);
static void GPIO_Config(void);
static void NVIC_Config(void);
static void System_Init(void);

static void SystemClock_Config(void)
{
    /* HSI -> PLL 64 MHz (no external crystal required, avoids unsupported PLL macros). */
    RCC->CR |= RCC_CR_HSION;
    while ((RCC->CR & RCC_CR_HSIRDY) == 0) {
    }

    FLASH->ACR = FLASH_ACR_PRFTBE | FLASH_ACR_LATENCY_2;

    RCC->CFGR = 0;
    RCC->CFGR |= RCC_CFGR_HPRE_DIV1;
    RCC->CFGR |= RCC_CFGR_PPRE1_DIV2;
    RCC->CFGR |= RCC_CFGR_PPRE2_DIV1;

    RCC->CFGR2 = RCC_CFGR2_PREDIV_DIV2;
    RCC->CFGR |= RCC_CFGR_PLLSRC_HSI_PREDIV | RCC_CFGR_PLLMUL16;

    RCC->CR |= RCC_CR_PLLON;
    while ((RCC->CR & RCC_CR_PLLRDY) == 0) {
    }

    RCC->CFGR &= ~RCC_CFGR_SW;
    RCC->CFGR |= RCC_CFGR_SW_PLL;
    while ((RCC->CFGR & RCC_CFGR_SWS) != RCC_CFGR_SWS_PLL) {
    }
}

static void GPIO_Config(void)
{
    RCC->AHBENR |= RCC_AHBENR_GPIOAEN | RCC_AHBENR_GPIOBEN;

    /* TIM1 on GPIOA: PA8/PA7/PA9/PA12 (CH1/CH1N/CH2/CH2N).
     * Build guide v3.1 lists PA10 for CH2N but PA10 has no TIM1_CH2N
     * alternate function on F303RE; PA12 is the correct pin. */
    GPIOA->MODER &= ~(GPIO_MODER_MODER7 | GPIO_MODER_MODER8 | GPIO_MODER_MODER9 |
                      GPIO_MODER_MODER12);
    GPIOA->MODER |= GPIO_MODER_MODER7_1 | GPIO_MODER_MODER8_1 | GPIO_MODER_MODER9_1 |
                     GPIO_MODER_MODER12_1;
    GPIOA->AFR[0] &= ~(0xFu << (7 * 4));
    GPIOA->AFR[1] &= ~((0xFu << ((8 - 8) * 4)) | (0xFu << ((9 - 8) * 4)) |
                      (0xFu << ((12 - 8) * 4)));
    GPIOA->AFR[0] |= (0x6u << (7 * 4));
    GPIOA->AFR[1] |= (0x6u << ((8 - 8) * 4)) | (0x6u << ((9 - 8) * 4)) |
                     (0x6u << ((12 - 8) * 4));

    /* TIM8 on GPIOB: PB6/PB3/PB8/PB0 (CH1/CH1N/CH2/CH2N).
     * Build guide v3.1 lists PC6-PC9 but only PC6 actually maps to TIM8_CH1;
     * PC7/PC8/PC9 map to CH2/CH3/CH4 not CH1N/CH2/CH2N. PB6/PB3/PB8/PB0 is
     * the correct combination for TIM8 complementary pairs on this package. */
    GPIOB->MODER &= ~(GPIO_MODER_MODER0 | GPIO_MODER_MODER3 | GPIO_MODER_MODER6 |
                      GPIO_MODER_MODER8);
    GPIOB->MODER |= GPIO_MODER_MODER0_1 | GPIO_MODER_MODER3_1 | GPIO_MODER_MODER6_1 |
                     GPIO_MODER_MODER8_1;
    GPIOB->AFR[0] &= ~((0xFu << (0 * 4)) | (0xFu << (3 * 4)) | (0xFu << (6 * 4)));
    GPIOB->AFR[1] &= ~(0xFu << ((8 - 8) * 4));
    GPIOB->AFR[0] |= (0x4u << (0 * 4)) | (0x4u << (3 * 4)) | (0x5u << (6 * 4));
    GPIOB->AFR[1] |= (0xAu << ((8 - 8) * 4));

    GPIOA->OTYPER &= ~(GPIO_OTYPER_OT_7 | GPIO_OTYPER_OT_8 | GPIO_OTYPER_OT_9 |
                       GPIO_OTYPER_OT_12);
    GPIOB->OTYPER &= ~(GPIO_OTYPER_OT_0 | GPIO_OTYPER_OT_3 | GPIO_OTYPER_OT_6 |
                       GPIO_OTYPER_OT_8);

    GPIOA->PUPDR &= ~(GPIO_PUPDR_PUPDR7 | GPIO_PUPDR_PUPDR8 | GPIO_PUPDR_PUPDR9 |
                      GPIO_PUPDR_PUPDR12);
    GPIOB->PUPDR &= ~(GPIO_PUPDR_PUPDR0 | GPIO_PUPDR_PUPDR3 | GPIO_PUPDR_PUPDR6 |
                      GPIO_PUPDR_PUPDR8);

    /* Medium speed reduces edge ringing on gate-drive traces while keeping timing margin. */
    GPIOA->OSPEEDR &= ~(GPIO_OSPEEDER_OSPEEDR7 | GPIO_OSPEEDER_OSPEEDR8 | GPIO_OSPEEDER_OSPEEDR9 |
                        GPIO_OSPEEDER_OSPEEDR12);
    GPIOA->OSPEEDR |= GPIO_OSPEEDER_OSPEEDR7_0 | GPIO_OSPEEDER_OSPEEDR8_0 |
                      GPIO_OSPEEDER_OSPEEDR9_0 | GPIO_OSPEEDER_OSPEEDR12_0;
    GPIOB->OSPEEDR &= ~(GPIO_OSPEEDER_OSPEEDR0 | GPIO_OSPEEDER_OSPEEDR3 | GPIO_OSPEEDER_OSPEEDR6 |
                        GPIO_OSPEEDER_OSPEEDR8);
    GPIOB->OSPEEDR |= GPIO_OSPEEDER_OSPEEDR0_0 | GPIO_OSPEEDER_OSPEEDR3_0 |
                      GPIO_OSPEEDER_OSPEEDR6_0 | GPIO_OSPEEDER_OSPEEDR8_0;

    /* FAULT_OUT on PB5: push-pull GPIO output, active-low. Driven HIGH here
     * (no fault) before the FSM starts; the FSM pulls it LOW on a latched
     * fault and releases it HIGH again on return to IDLE. */
    GPIOB->MODER &= ~GPIO_MODER_MODER5;
    GPIOB->MODER |= GPIO_MODER_MODER5_0;            /* general-purpose output */
    GPIOB->OTYPER &= ~GPIO_OTYPER_OT_5;             /* push-pull */
    GPIOB->PUPDR &= ~GPIO_PUPDR_PUPDR5;
    GPIOB->OSPEEDR &= ~GPIO_OSPEEDER_OSPEEDR5;      /* low speed is fine */
    GPIOB->BSRR = (1u << FAULT_OUT_PIN);            /* HIGH = no fault */
}

static void NVIC_Config(void)
{
    NVIC_SetPriority(TIM1_UP_TIM16_IRQn, 0);
    NVIC_EnableIRQ(TIM1_UP_TIM16_IRQn);
}

static void System_Init(void)
{
    SystemClock_Config();
    (void)SysTick_Config(TIMER_CLK_HZ / 1000u);
    NVIC_SetPriority(SysTick_IRQn, 15u);
    GPIO_Config();
    Pwm_Init();
    SPI_MCP3201_Init();
    UART_Init();
    Sensing_Init();
    NVIC_Config();
    FSM_Init();
}

int main(void)
{
    System_Init();

    while (1) {
        FSM_Run();
    }
}

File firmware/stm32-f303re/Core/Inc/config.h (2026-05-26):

#ifndef CONFIG_H
#define CONFIG_H

#include "stm32f3xx.h"
#include <stdint.h>

#define CONFIG_SYSCLK_HZ 64000000u
#define CONFIG_APB1_CLK_HZ 32000000u
#define CONFIG_APB1_TIMER_CLK_HZ 64000000u

#define CONFIG_UART_BAUD 115200u
#define CONFIG_SENSE_HZ 1000u
#define CONFIG_TELEMETRY_PERIOD_MS 50u

#define CONFIG_IIR_ALPHA 0.1f
#define CONFIG_ADC_COUNTS 4096.0f
#define CONFIG_VDC_DIVIDER_GAIN (105.1f / 5.1f)
#define CONFIG_VDC_ADC_REF 5.0f
#define CONFIG_CUR_ADC_REF 3.3f
#define CONFIG_ACS_DIVIDER_GAIN 0.6f
#define CONFIG_ACS_ZERO_VOLTS 2.5f
#define CONFIG_ACS_SENSITIVITY_V_PER_A 0.1f

/* MCP3201 pins. SCK is bit-banged on PA5. Each MCP3201 still has its own
 * chip-select (CS_DC1/DC2/CUR) so the firmware can address them individually.
 *
 * MISO topology on this board: TWO physical MISO return lines, not three.
 *   - MISO_DC1 (PA6): the lower-bridge island, DC1 ADC only.
 *   - MISO_DC2 / MISO_CUR (PC3): the upper-bridge island carries BOTH the
 *     DC2 ADC and the current ADC on a single wire-shared isolated return.
 * Because DC2 and CUR share PC3, SPI_MCP3201_Read must read strictly one
 * channel at a time (one CS asserted) — see spi_mcp3201.c. PC4 is unused. */
#define MCP3201_SCK_PORT GPIOA
#define MCP3201_SCK_PIN 5u
#define MCP3201_MISO_DC1_PORT GPIOA
#define MCP3201_MISO_DC1_PIN 6u
#define MCP3201_CS_DC1_PORT GPIOC
#define MCP3201_CS_DC1_PIN 0u
#define MCP3201_CS_DC2_PORT GPIOC
#define MCP3201_CS_DC2_PIN 1u
#define MCP3201_CS_CUR_PORT GPIOC
#define MCP3201_CS_CUR_PIN 2u
#define MCP3201_MISO_DC2_PORT GPIOC
#define MCP3201_MISO_DC2_PIN 3u
#define MCP3201_MISO_CUR_PORT GPIOC
#define MCP3201_MISO_CUR_PIN 3u   /* shared with DC2 on this board */

/* Hardware fault output. Driven LOW when a fault is latched, HIGH otherwise
 * (active-low, per build guide v3.1 header pin 16 "FAULT_OUT"). Wire the
 * PCB's FAULT_OUT trace to this STM32 pin. */
#define FAULT_OUT_PORT GPIOB
#define FAULT_OUT_PIN 5u

#define UART_VCP_PORT GPIOA
#define UART_VCP_TX_PIN 2u
#define UART_VCP_RX_PIN 3u

/* 32 NOPs plus GPIO overhead keeps the bit-banged SCK below 1 MHz. The
 * isolated 6N137 path has propagation delay in both directions, so this margin
 * is intentional instead of running near the MCP3201's absolute limit. */
#define MCP3201_HALF_PERIOD_DELAY_CYCLES 32u

typedef enum {
    MODE_FULL = 0,
    MODE_DC_ONLY = 1,
    MODE_CURRENT_ONLY = 2,
    MODE_OPEN_LOOP = 3,
    MODE_DC1_ONLY = 4,
    MODE_DC2_ONLY = 5,
    MODE_COUNT
} sensing_mode_t;

#define SENSOR_MASK_DC1 0x01u
#define SENSOR_MASK_DC2 0x02u
#define SENSOR_MASK_CUR 0x04u
#define SENSOR_MASK_ALL (SENSOR_MASK_DC1 | SENSOR_MASK_DC2 | SENSOR_MASK_CUR)

#endif /* CONFIG_H */

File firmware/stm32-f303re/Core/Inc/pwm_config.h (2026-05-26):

#ifndef PWM_CONFIG_H
#define PWM_CONFIG_H

#include <stdint.h>

/* Modulator selection.
 *   STAIR     - bench-validated 500 Hz quantize-to-5-levels (NOT real PWM;
 *               levels are held statically, only 1% bootstrap-refresh pulses).
 *               Bridge 1 carries every +/-1 step alone -> thermal imbalance.
 *   STAIR_ALT - same staircase output as STAIR, but the bridge that handles
 *               the +/-1 step alternates every time the level is re-entered.
 *               Same "not real PWM" property as STAIR; thermals balance.
 *   PSC       - unipolar phase-shifted-carrier SPWM at the configured FSW.
 *               REAL PWM. Produces 5 distinct cascade levels in hardware
 *               via the 90 deg carrier shift between TIM1 and TIM8. This
 *               is what the project requires for the unfiltered 5-level
 *               output demo. */
typedef enum {
    MODULATOR_STAIR = 0,
    MODULATOR_PSC = 1,
    MODULATOR_STAIR_ALT = 2,
    MODULATOR_COUNT
} modulator_type_t;

/* Bridge selection for single-bridge test mode. The inactive bridge has all
 * four MOSFETs forced to the "both LS on, both HS off" freewheel state so its
 * contribution to the cascaded output is ~0 V. The active bridge produces its
 * normal 3-level output (-Vdc / 0 / +Vdc). */
typedef enum {
    BRIDGE_BOTH = 0,
    BRIDGE_B1_ONLY = 1,
    BRIDGE_B2_ONLY = 2,
    BRIDGE_COUNT
} bridge_select_t;

typedef struct {
    modulator_type_t modulator;
    uint32_t switching_freq_hz;
    bridge_select_t bridge_select;
    float modulation_index;
    float fundamental_freq_hz;
} pwm_config_t;

/* Safe defaults. With no UART input, the firmware boots to these and
 * (optionally) auto-starts after a delay — see FSM auto-start logic. */
#define PWM_DEFAULT_MODULATOR       MODULATOR_STAIR
#define PWM_DEFAULT_SWITCHING_HZ    500u
#define PWM_DEFAULT_BRIDGE_SELECT   BRIDGE_BOTH
#define PWM_DEFAULT_MI              0.95f
#define PWM_DEFAULT_FUNDAMENTAL_HZ  50.0f

/* Bounds for runtime config. Rejected by UART parser if outside. */
#define PWM_FSW_MIN_HZ              100u
#define PWM_FSW_MAX_HZ              20000u
#define PWM_FUNDAMENTAL_MIN_HZ      10.0f
#define PWM_FUNDAMENTAL_MAX_HZ      400.0f

/* Auto-start: if no UART byte is received within this many ms after boot,
 * the FSM issues its own START so the inverter runs standalone with defaults.
 * Any received UART byte cancels auto-start permanently. */
#define PWM_AUTOSTART_DELAY_MS      3000u

#endif /* PWM_CONFIG_H */

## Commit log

2026-05-16 mcp3201 fix and linting and changleog added.
    [config.h, fsm.c, protection.h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]
2026-05-16 SPI wrong fix reverted
    [main.c, spi_mcp3201.c]
2026-05-16 PSC-PWM rewrite with runtime config and auto-start
2026-05-16 Hardening of psc pwm and alternate stair fallback
2026-05-26 chore: initialize chb-inverter monorepo skeleton
    Scaffolds the consolidated repository structure for the 5-Level Cascaded
    H-Bridge Inverter graduation project. Top-level metadata only — content
    phases follow.
    What's in:
    - Directory tree per the master plan (hardware, firmware, simulation,
    experimental, docs, tools, tests, .github).
    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
2026-05-26 docs(tracker): log Phase 0 completion — repo created and pushed
2026-05-26 feat(docs,ci): Phase 1 — MkDocs Material site + GitHub Actions
    Local docs build (`py -3.12 -m mkdocs build --strict`) passes clean.
    - mkdocs.yml — Material theme, slate dark default with light/auto toggle,
    primary teal + accent amber. Plugins: awesome-pages, glightbox,
    git-revision-date-localized, include-markdown, mermaid2, table-reader.
    Markdown extensions per Material's recommended baseline.
    - pyproject.toml — pinned docs deps (mkdocs-material 9.5, friends) and a
    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
2026-05-26 docs(firmware,bringup,dashboard): Phase 2 content
    Render the firmware-tree documentation into the MkDocs site after the
    git subtree import. mkdocs build --strict passes; docs-link-check.py
    finds no broken in-tree links.
    Firmware section (handwritten — accurate links to GitHub source):
    - overview.md: module map, control flow, footprint.
    - pin-map.md: as-wired GPIO with the v3.1 errata side-by-side.
    - state-machine.md: Mermaid FSM diagram + per-mode protection table.
    - uart-protocol.md: command set, telemetry frame, line prefixes
    (was a Phase 1 stub).
    - modulators.md: STAIR / PSC / STAIR_ALT, phase-lock diagnostic
    (was a Phase 1 stub).
    - protection.md: VNOM-scaled thresholds, sensing mo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
2026-05-26 feat(hw,sim,docs): Phase 3 + Phase 4 — hardware + simulation from Drive
    Pulled the as-built hardware project, the Simulink models, and the report
    PDFs from the team's Google Drive folder. Wrote the matching MkDocs pages.
    mkdocs build --strict passes; docs-link-check.py is clean except for
    2 false-positive include-markdown rewrites of source-file links.
    Hardware:
    - hardware/single-bridge-v4/kicad/: full CHB_INVERTER KiCad 9 project —
    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
    [5v-15v_sch.kicad_sch, CHB_BOM_v3_1.xlsx, CHB_INVERTER.kicad_pcb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]
2026-05-26 docs: Phase 5 Pass 1 — design notes, iteration history, final-report skeleton
    mkdocs --strict passes. Per master plan, the final report's expansion
    (Pass 2) is held until the user signs off on the skeleton structure.
    Design notes (5 — all expanded to 1–2 pages each):
    - bootstrap-fundamentals.md: how bootstrap works on IR2110, why it fails
    for floating bridges, the firmware's 95% duty clamp + 6 ms precharge,
    why this project uses isolated 15V instead.
    - chb-isolation.md: what "floating" means in CHB, the 3 failure modes
    without isolation (gate drive, common-mode coupling, sensing), the
    4 isolation barriers in the as-built (TLP250, B0515S, 6N137 SCK/CS,
    6N137 MISO), per-bridge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
2026-05-26 feat: Phase 6 (RISC-V SoC) + Phase 7 (README + About pages)
    Processed the raw-files/ folder. Now contains nothing the repo needs.
    experimental/risc-v-soc/ — full tape-out package:
    - README.md: architecture overview with per-block Mermaid diagram, GDSII
    index, render gallery pointer, how-to-open instructions, PDK + license
    notes, and the explicit "not in graduation report" framing.
    - rtl/: 20 Verilog files — custom RV32IM core (5-state multi-cycle,
    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
    [rv32im_soc_with_integrated_core.sdf]
2026-05-26 docs(readme): use 100V scope PNG as hero, demo-poster + PCB render in quick links
    User feedback: replace the demo-stand hero with the actual headline result
    (100 V output with 5 distinct cascade levels) and make the quick-link tile
    images more topically related.
    README changes:
    - Hero image: 100v-output-5-levels.png (the project deliverable on the
    scope) with a caption identifying it as such.
    - Quick-link tile images:
    - Final report tile -> demo-poster.jpeg (the project poster image)
    - Hardware tile -> hardware/single-bridge-v4/renders/pcb-3d-render.png
    (the actual board, not an abstract schematic block diagram)
    - Bring-up tile (new, 6th tile) -> scope-pwm-cascade-output.jpeg
    -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
2026-05-26 docs: polish pass — hero images on every section, content fixes, scope captures inline
    mkdocs --strict passes; site now consistently leads with a relevant image
    per section.
    Section index hero images (figure + caption per page):
    - docs/index.md -> 100v-output-5-levels.png (headline result)
    - docs/hardware/index.md -> pcb-top-down-kicad.jpeg (the as-built board)
    - docs/firmware/index.md -> stm32-only-diagram.png (firmware architecture)
    - docs/dashboard/index.md -> lab-testing-setup-hero.jpeg (dashboard on bench)
    - docs/simulation/index.md -> pwm-output.png (early Simulink trace)
    - docs/bringup/index.md -> lab-power-sources-test.jpeg (bench supplies)
    - docs/design-notes/i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
2026-05-26 feat: Phase 5 Pass 2 + Phase 8 — full final report + handover document
    mkdocs build --strict passes; only the 2 known include-markdown false
    positives remain in the link-checker output.
    Phase 5 Pass 2 — final report expansion:
    - docs/final-report/index.md grown from skeleton stubs to the full
    consolidated graduation report.
    - 10 sections per master plan: Abstract & summary, System architecture,
    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
2026-05-26 docs(readme): expand inverter-pcb image caption with hardware specifics
    The user-inserted hardware-module image at the top of the README had
    a bare 'Hardware Module' caption. Replaced with a technically dense
    caption that names: 4-layer JLCPCB stack-up, IRFB4110 power MOSFETs,
    TLP250 optical gate drive + B0515S isolated 15 V rail, bit-banged
    MCP3201 sensing through 6N137 optocouplers, and the relationship to
    the 100 V cascade output below.
    alt text also strengthened from 'Half-bridge module — fully populated
    hardware' to name the specific parts that distinguish the as-built
    design.
2026-05-26 fix(docs): render Material icons, fetch LFS in CI, remove Getting-started tab
    Three production-site bugs the user spotted:
    1. Material icon shortcodes (:material-cube-outline:, :octicons-arrow-right-24:,
    etc.) rendered as raw text on the docs landing page because pymdownx.emoji
    was missing from mkdocs.yml markdown_extensions. Without the emoji
    extension, the icon shortcodes never get processed into <svg> tags, and
    the {.lg .middle} attr_list syntax has nothing to attach to either.
    Added the Material-recommended emoji block:
    - pymdownx.emoji:
    emoji_index: !!python/name:material.extensions.emoji.twemoji
    emoji_generator: !!python/name:material.extensions.e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
2026-05-26 docs: hero swap, broken-image fix, 9 new photos, 6 roadmap pages expanded
    mkdocs --strict passes; only the 2 known include-markdown false
    positives remain in link-check.
    Docs landing hero swap (per user request):
    - docs/index.md hero changed from 100v-output-5-levels.png to
    inverter-pcb.png (the populated single-bridge v4 PCB module).
    - The 100V scope capture is still used elsewhere — final report,
    populated-photos, modulators, psc-vs-lspwm, thd-analysis,
    iteration-4 — so it has plenty of presence in the docs without
    being on the landing page.
    Broken-image fix on About pages (raw <img src="../assets/...">
    breaks at deeper URL levels because the browser resolves relative to
    the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
2026-05-26 docs(landing): move inverter-pcb hero from top to after the team image
    Per user request — the page now flows: title -> hook -> status -> quick
    links -> section table -> team (with group photo) -> Hacettepe line ->
    inverter-pcb image as the closing visual. The PCB image still names the
    key as-built design points in its caption.
2026-05-26 fix(report): Turkish font + dashes + tables + logo + diagrams + June date
    Six fixes to the ELE 402 final-report PDF generator after first-pass review:
    1. Turkish character support (was rendering as black boxes).
    Helvetica is a standard PDF Type 1 font and does not include
    ı, ş, ğ, ç, ü, ö. Registered Arial from C:/Windows/Fonts
    (arial.ttf + arialbd.ttf + ariali.ttf + arialbi.ttf) via
    reportlab's TTFont + registerFontFamily. Cereyan Hacıları,
    Mücahit Aydın, Rasım Doğan, Koçak now render correctly. Falls
    back to DejaVuSans on Linux/Mac, and to Helvetica with a
    warning if nothing is available.
    2. Removed all em-dashes (—) and en-dashes (–) globally.
    Ad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
2026-05-26 fix(report): footer uses Arial (Turkish chars); System block heading + figure kept on same page
    Two hiccups from second-pass review:
    1. Footer rendered 'Cereyan Hac■lar■' (black-box characters)
    because FooterCanvas._draw_footer() was using setFont('Helvetica', 9)
    directly. Helvetica is a standard PDF Type 1 font without Turkish
    character support. Switched to setFont(FONT, 9) which uses the
    registered Arial face, so the footer reads 'Cereyan Hacıları'
    correctly on every page. Also swapped the em-dashes in the footer
    text for plain hyphens to match the rest of the report.
    2. The 'System block diagram' H3 heading was landing at the bottom of
    page 7 with the figure p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
2026-05-26 feat(report): individual ELE 402 project logbooks for all 4 team members
    Per ELE 402 course requirement that each team member maintains an
    individual logbook reflecting their personal perspective on the project.
    Modelled on the ELE 401 Fall 2025 logbook example the user provided.
    Generated PDFs (5-6 pages each):
    - ELE402_Spring2026_Logbook_FurkanEmirAksel.pdf (6 pp, 220357099)
    - ELE402_Spring2026_Logbook_AhmetKocak.pdf (5 pp)
    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
